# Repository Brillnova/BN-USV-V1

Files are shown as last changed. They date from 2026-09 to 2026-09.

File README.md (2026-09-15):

# BN-USV V1

BN-USV V1 is an experimental unmanned surface vehicle reference prototype by Brillnova. It was developed to validate the control architecture, navigation software and on-water behavior of a Raspberry Pi and ESP32-based USV.

V1 is **not a commercial product**, is **not for sale**, and is **not a ready-to-print DIY kit**. It is shared as a technical reference. The hull requires substantial post-processing, bonding and waterproofing, and is not optimized for easy reproduction.

For the next platform direction and Brillnova updates, see the [Brillnova website](https://brillnova.net), [GitHub](https://github.com/Brillnova), and [YouTube](https://www.youtube.com/@Brillnova).

## Included in this release

- Raspberry Pi navigation and control reference software
- ESP32 propulsion-control firmware, with OTA disabled until local credentials are configured
- Minimal dependency list and local configuration template
- V1 reference hull STL meshes and a FreeCAD assembly composed from those meshes
- Assembly and reference-hull licensing notes

## Not included

- V2 materials, source code or designs
- PCB designs, original CAD, manufacturing files or internal design documents
- Raw field logs, real waypoints, calibration values and network credentials
- BOM and wiring-diagram files; these are not part of this initial release

## Quick start

1. Review [assembly notes](docs/ASSEMBLY_NOTES.md) and the limitations below.
2. Copy `software/config.example.py` to `software/config.py`, then enter local ports, waypoints and calibration values. Do not commit this file.
3. Install the Python dependencies: `python3 -m pip install -r software/requirements.txt`.
4. Review the pin assignments and safety behavior in `firmware/BN_USV_V0.3.1/BN_USV_V0.3.1.ino` before flashing it to an ESP32.
5. Keep OTA disabled or set local credentials only in your working copy.

The software expects sensor hardware and system dependencies not bundled in this repository. This is a reference implementation, not a turnkey installation guide.

## Known limitations

- Hull assembly requires significant bonding and waterproofing.
- The design has limited modularity and difficult access to internal components.
- Wiring is prototype-oriented.
- Assembly support, success guarantees and performance guarantees are not provided.
- The BOM for future releases will include only parts directly tested by Brillnova; alternatives are not validated.

## Licensing

Unless a file states otherwise, the software in this repository is released under the [MIT License](LICENSE).

The V1 reference hull meshes and the FreeCAD mesh assembly are licensed separately under [CC BY-NC-SA 4.0](docs/REFERENCE_HULL_FILES.md). Branding, photographs and videos are not licensed for reuse by the software license.

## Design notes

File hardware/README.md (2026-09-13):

# V1 reference hull files

`stl/` contains the V1 hull mesh files used for the reference prototype.

`assembly/BN_USV_V1.FCStd` is a FreeCAD project composed from those STL meshes. It is included for reference and mesh arrangement; it is not the original parametric CAD source.

See [Reference hull files](../docs/REFERENCE_HULL_FILES.md) for the CC BY-NC-SA 4.0 terms, scope and attribution requirements. V1 requires substantial post-processing, bonding and waterproofing and is not a turnkey DIY kit.

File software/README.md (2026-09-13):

# V1 reference software

This folder contains the Raspberry Pi-side reference implementation for V1 navigation, sensor input, propulsion commands and runtime logging. It is intended for inspection and adaptation, not as a turnkey deployment package.

## Before running

Copy `config.example.py` to `config.py`, then set your local serial ports, waypoint coordinates and magnetometer calibration values. `config.py` is deliberately ignored by Git so local settings and test locations are not published.

Install the minimal Python dependencies with:

```bash
python3 -m pip install -r requirements.txt
```

`main_v4.py` is the main application entry point. It expects the configured sensors and an ESP32 connection to be available.

## Files

| File | Purpose |
| --- | --- |
| `main_v4.py` | Runs the V1 mission loop: reads sensors, calculates navigation and control output, sends commands to the ESP32, and records state. |
| `config.example.py` | Template for local ports, waypoints, arrival radius and magnetometer calibration. Copy it to `config.py` before use. |
| `gps.py` | Reads and parses GPS/NMEA position, speed and course information. |
| `mag.py` | Reads the LIS3MDL magnetometer and applies heading calibration values. |
| `mag_calibration.py` | Updates magnetometer heading calibration from GPS-course comparisons when suitable data is available. |
| `imu.py` | Reads IMU acceleration and angular-rate data. |
| `battery.py` | Reads the INA226 battery monitor and estimates voltage, current and state of charge. |
| `navigation.py` | Calculates distance, bearing and normalized heading error to the current waypoint. |
| `controller.py` | Converts distance and heading error into throttle and steering commands. |
| `esp_link.py` | Exchanges JSON-line control commands and telemetry with the ESP32 over serial. |
| `logger.py` | Writes navigation, sensor, battery and control state to CSV and JSONL logs. |
| `requirements.txt` | Minimal Python dependency list for the reference software. |

## Operational notes

The reference controller and all safety thresholds need review and testing for the vessel, sensors and operating conditions in use. Test with propulsion safely restrained or disconnected before water operation. Raw logs are not included in this public repository.

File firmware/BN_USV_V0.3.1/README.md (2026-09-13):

# BN_USV_V0.3.1 ESP32 firmware

`BN_USV_V0.3.1.ino` is the V1 ESP32-S3 reference firmware. It reads RC PWM input, drives the left and right ESC outputs, accepts serial commands from the Raspberry Pi, and emits JSON-line telemetry.

## What it does

- Reads RC steering, throttle and mode-switch channels.
- Drives separate left and right ESC PWM outputs.
- Accepts `cmd_manual` JSON-line commands from the Raspberry Pi over USB serial.
- Applies manual override, neutral re-arm and command-freshness checks.
- Moves to a neutral/failsafe state when RC or Pi commands time out.
- Reports periodic `telemetry_status` messages over serial.
- Supports optional Arduino OTA updates, disabled by default in this public release.

## Before uploading

Review the user-configuration section near the top of the sketch for your hardware:

| Setting | Default | Purpose |
| --- | --- | --- |
| `RC_CH1_PIN`, `RC_CH2_PIN`, `RC_CH4_PIN` | `4`, `5`, `6` | RC steering, throttle and mode-switch PWM input pins. |
| `ESC_L_PIN`, `ESC_R_PIN` | `1`, `2` | Left and right ESC PWM output pins. |
| `UART_BAUD` | `115200` | USB serial speed used for Raspberry Pi communication. |
| `PWM_MIN_US`, `PWM_MAX_US`, `PWM_NEU_US` | `1000`, `2000`, `1500` | ESC output range and neutral value. |
| `RC_TIMEOUT_MS`, `CH4_TIMEOUT_MS`, `PI_TIMEOUT_MS` | `300`, `500`, `500` | Input freshness limits that trigger safety behavior. |
| `OTA_SSID`, `OTA_PASSWORD` | empty | OTA is disabled while the SSID is empty. Keep any local credentials out of Git. |

The default pins and thresholds came from the V1 prototype. They are not universal values and must be checked against the actual board, receiver, ESCs and propulsion system.

## Dependencies and upload

Install the Arduino core for ESP32 and the `ESP32Servo` library in the Arduino IDE or Arduino CLI environment, then select the appropriate ESP32-S3 board and serial port before uploading. `WiFi.h` and `ArduinoOTA.h` come from the ESP32 Arduino core.

Keep OTA disabled unless you have configured local credentials in an uncommitted working copy.

## Safety check

Before connecting propulsion, confirm the configured pin mapping, neutral PWM value, RC mode behavior and serial-command timeout. Test with propellers removed or the vessel safely restrained. This is prototype firmware and does not provide a guarantee of safe operation in another hardware configuration.

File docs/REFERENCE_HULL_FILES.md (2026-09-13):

# V1 reference hull files

This release includes the V1 reference hull mesh files in [`hardware/stl`](../hardware/stl), plus the [`BN_USV_V1.FCStd`](../hardware/assembly/BN_USV_V1.FCStd) FreeCAD assembly and a preview image in [`hardware/assembly`](../hardware/assembly).

The FreeCAD project is an assembly of the released STL meshes. It is provided for viewing and arranging those meshes; it is not the original parametric CAD source.

## License and scope

The STL files in `hardware/stl` and the `hardware/assembly/BN_USV_V1.FCStd` assembly are **V1 Reference Hull Files** and are licensed under [CC BY-NC-SA 4.0](https://creativecommons.org/licenses/by-nc-sa/4.0/).

This permits noncommercial personal fabrication, modification and redistribution, provided that you:

- Credit **Brillnova**, retain a link to the source and license, and identify any changes.
- Distribute modified V1 Reference Hull Files under the same CC BY-NC-SA 4.0 license.
- Do not use the files for commercial purposes or imply Brillnova endorsement.

Suggested attribution:

> BN-USV V1 Reference Hull Files by Brillnova. Source: https://github.com/Brillnova/BN-USV-V1. Licensed under CC BY-NC-SA 4.0: https://creativecommons.org/licenses/by-nc-sa/4.0/. Changes: [describe changes, or state unmodified].

Original parametric CAD, PCB designs, other manufacturing files and all V2 designs are excluded from this license unless Brillnova separately releases them.

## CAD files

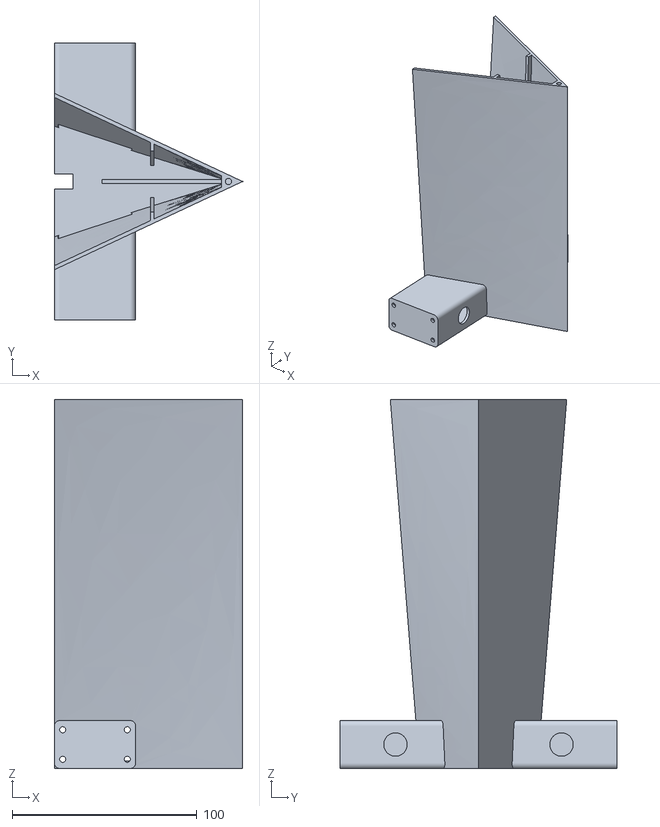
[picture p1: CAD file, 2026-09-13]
hardware/stl/Main Hull 3_4.stl
102.0 x 150.0 x 200.0

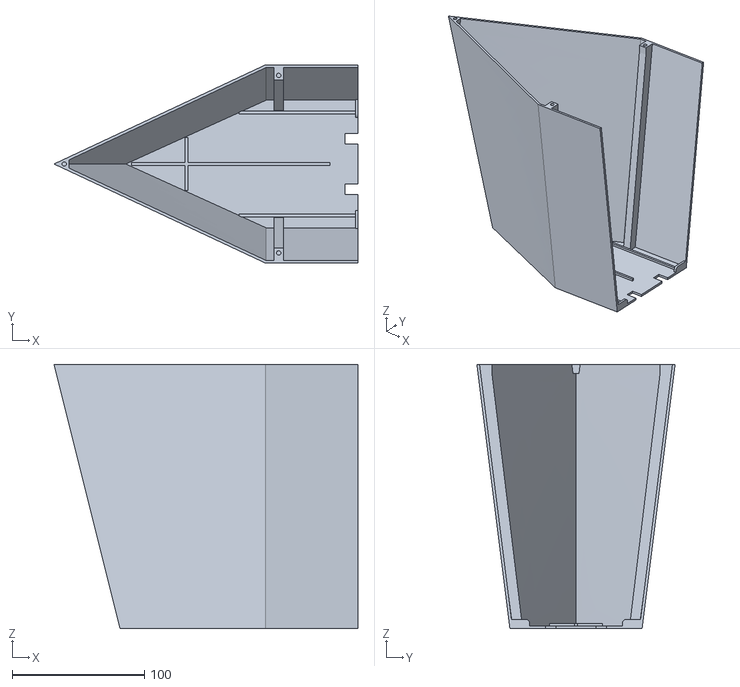
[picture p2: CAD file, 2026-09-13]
hardware/stl/Main Hull 1_4.stl
230.0 x 150.0 x 200.0

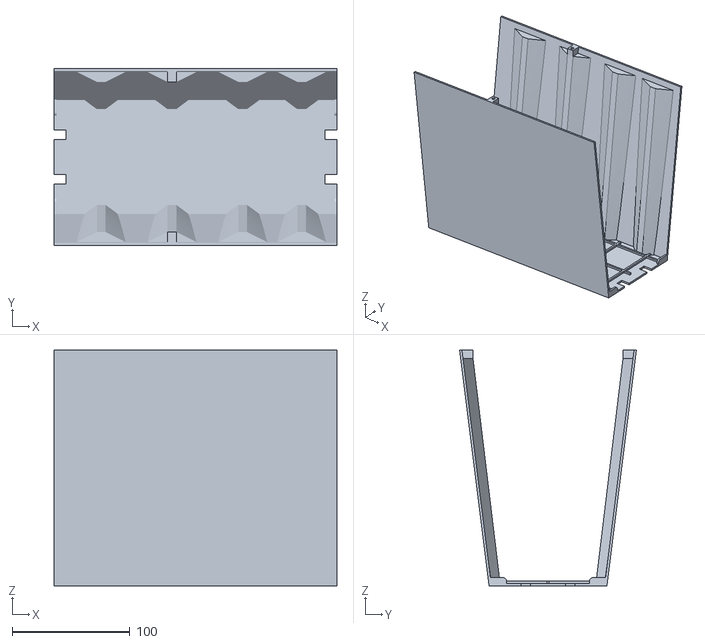
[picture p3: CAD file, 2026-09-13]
hardware/stl/Main Hull 4_4.stl
240.0 x 150.0 x 200.0

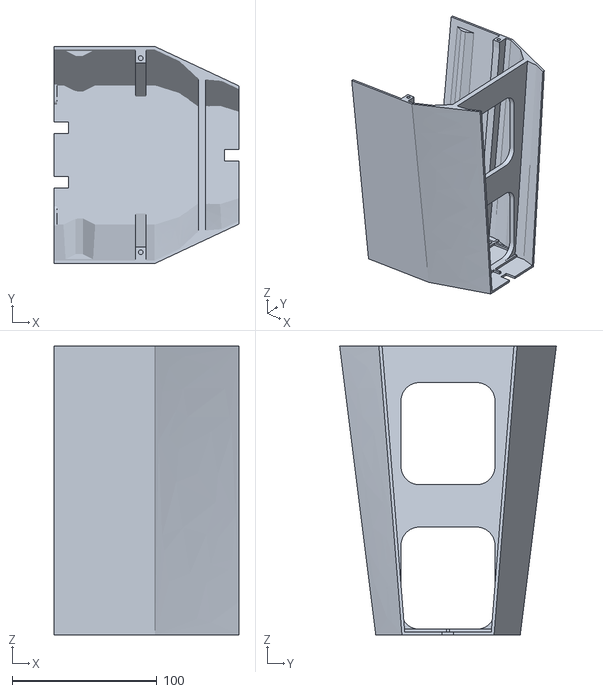
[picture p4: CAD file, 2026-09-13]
hardware/stl/Main Hull 2_4.stl
128.0 x 150.0 x 200.0

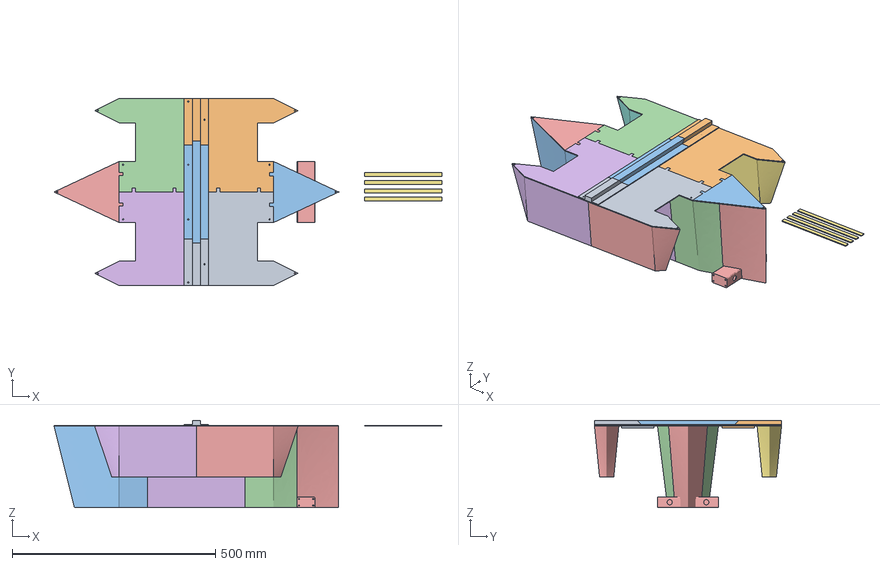
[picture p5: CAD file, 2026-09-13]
hardware/assembly/BN_USV_V1.FCStd
954.0 x 460.0 x 214.0 mm
Hatch Cover 1/6
Hatch Cover 2/6
Hatch Cover_3/6
Hatch Cover_4/6
Hatch Cover_5/6
Hatch Cover_6/6
PCB Mounting Plate 2_2
PCB Mounting Plate 1_2
Hatch Cover Transverse Stiffener 4_4
Hatch Cover Transverse Stiffener 3_4
Hatch Cover Transverse Stiffener 2_4
Hatch Cover Transverse Stiffener 1_4
Outrigger Hull 1_4
Outrigger Hull 2_4
Outrigger Hull 3_4
Outrigger Hull 4_4
Outrigger Stiffener
Hull Joining Sleeve 1_5
Main Hull 1_4
Main Hull 2_4
Main Hull 3_4
Main Hull 4_4
Hull Joining Sleeve 2_5
Hull Joining Sleeve 3_5
Hull Joining Sleeve 4_5
Hull Joining Sleeve 5_5

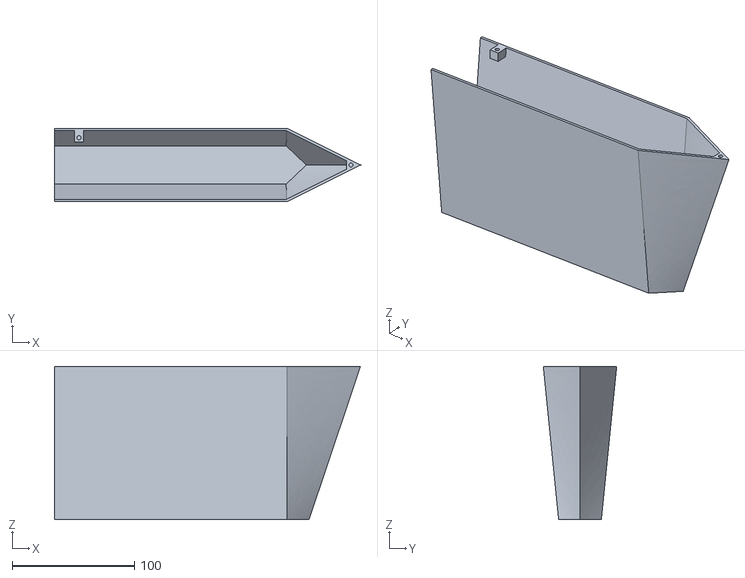
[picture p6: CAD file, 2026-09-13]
hardware/stl/Outrigger Hull 1_4.stl
250.0 x 60.0 x 125.0

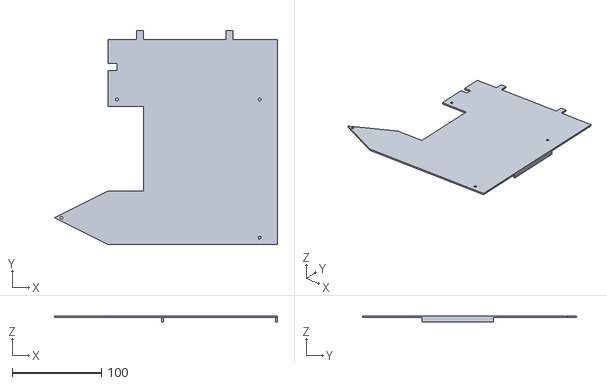
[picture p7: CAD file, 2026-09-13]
hardware/stl/Hatch Cover 6_6.stl
250.0 x 240.0 x 7.00

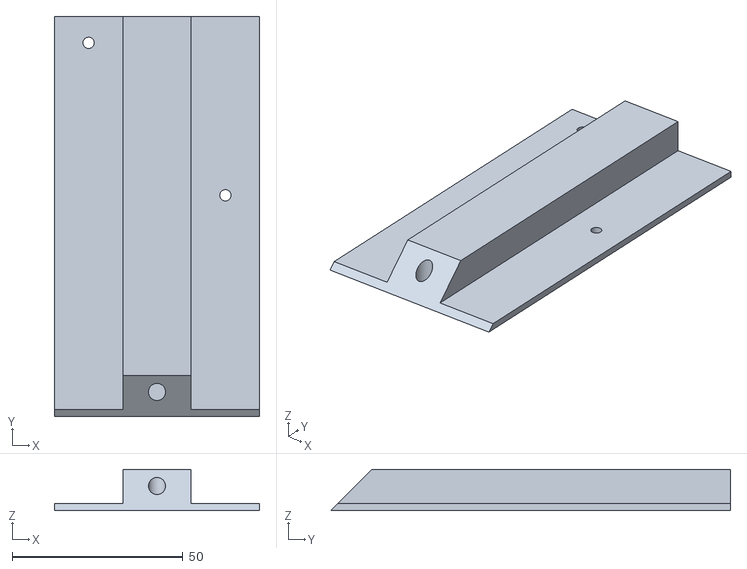
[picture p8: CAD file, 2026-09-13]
hardware/stl/Hatch Cover Transverse Stiffener 3_4.stl
60.0 x 117.0 x 12.0

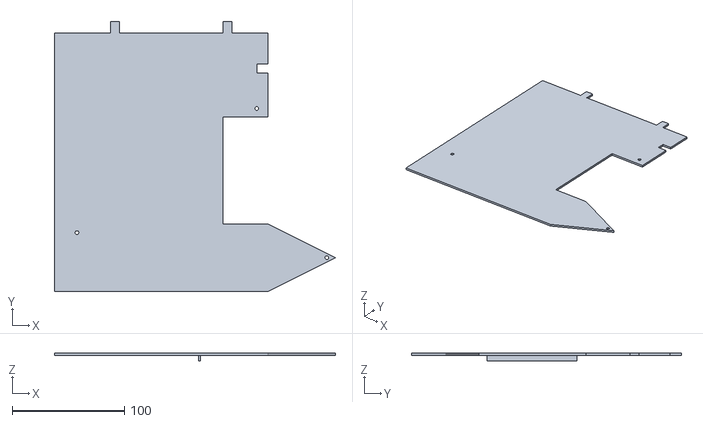
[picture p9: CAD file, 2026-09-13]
hardware/stl/Hatch Cover 1_6.stl
250.0 x 240.0 x 7.00

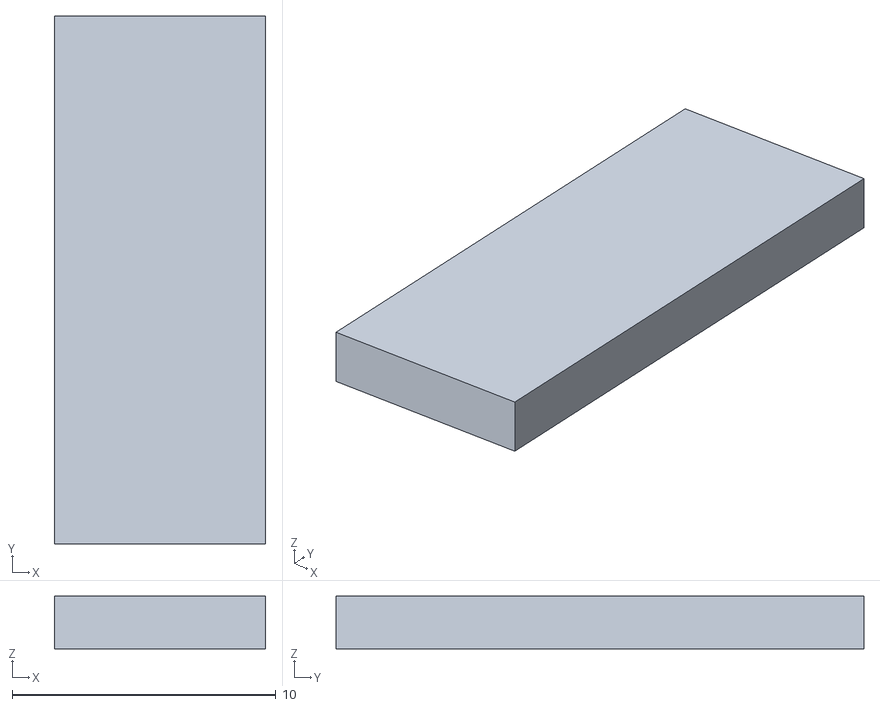
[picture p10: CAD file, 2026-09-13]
hardware/stl/Hull Joining Sleeve 1_5.stl
8.00 x 20.0 x 2.00

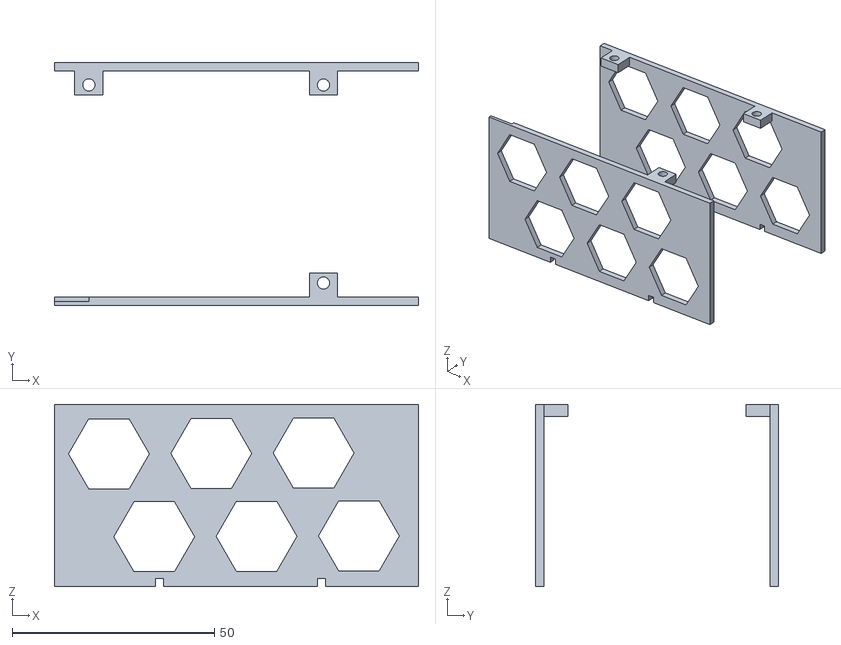
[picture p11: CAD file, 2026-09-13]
hardware/stl/PCB Mounting Plate 2_2.stl
90.0 x 60.0 x 45.0

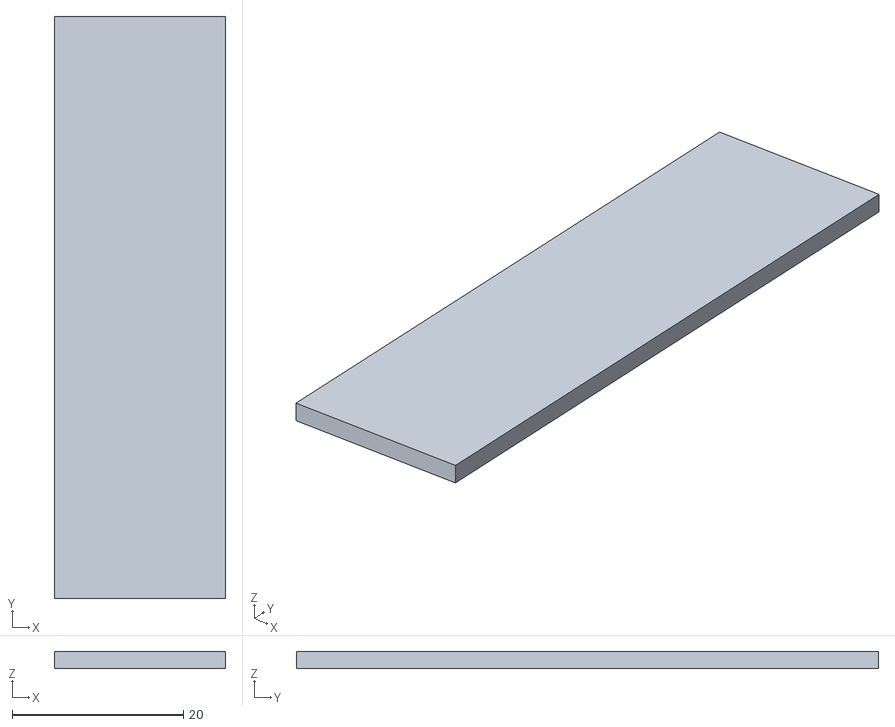
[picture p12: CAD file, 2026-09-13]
hardware/stl/Hull Joining Sleeve 4_5.stl
20.0 x 68.0 x 2.00

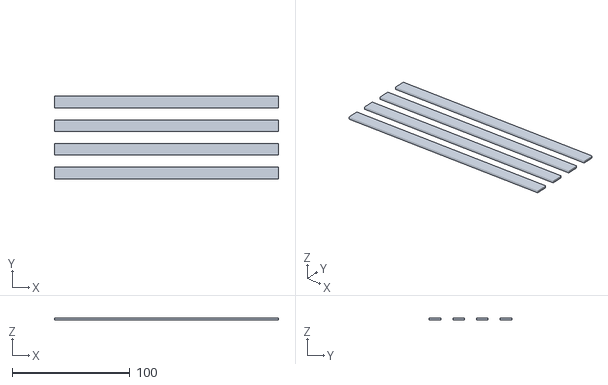
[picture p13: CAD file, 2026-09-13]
hardware/stl/Hull Joining Sleeve 2_5.stl
190.0 x 70.0 x 2.00

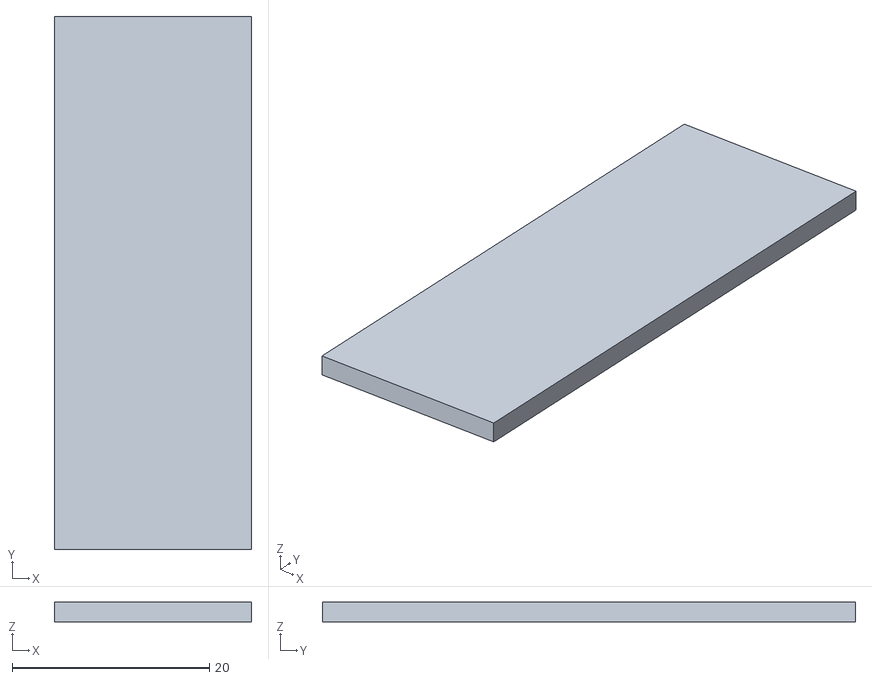
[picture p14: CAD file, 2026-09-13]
hardware/stl/Hull Joining Sleeve 5_5.stl
20.0 x 54.0 x 2.00

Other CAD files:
hardware/stl/Outrigger Hull 4_4.stl
hardware/stl/Outrigger Hull 3_4.stl
hardware/stl/Hull Joining Sleeve 3_5.stl
hardware/stl/Hatch Cover 5_6.stl
hardware/stl/Hatch Cover 2_6.stl
hardware/stl/Hatch Cover 3_6.stl
hardware/stl/Hatch Cover 4_6.stl
hardware/stl/Hatch Cover Transverse Stiffener 1_4.stl
hardware/stl/Hatch Cover Transverse Stiffener 2_4.stl
hardware/stl/Hatch Cover Transverse Stiffener 4_4.stl
hardware/stl/Outrigger Hull 2_4.stl
hardware/stl/PCB Mounting Plate 1_2.stl

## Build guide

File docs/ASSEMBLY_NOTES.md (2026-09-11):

# Assembly notes

V1 is an experimental reference prototype. Its hull requires substantial post-processing, bonding and waterproofing. The project does not provide individual build support or guarantees of assembly success, seaworthiness or performance.

Use only a configuration appropriate for your operating environment. Inspect every waterproofing point and confirm neutral propulsion output, manual override and failsafe behavior before testing. Conduct initial tests in a controlled environment and follow applicable local rules.

The BOM for a future release will list only components tested by Brillnova. Substitute parts are not validated.

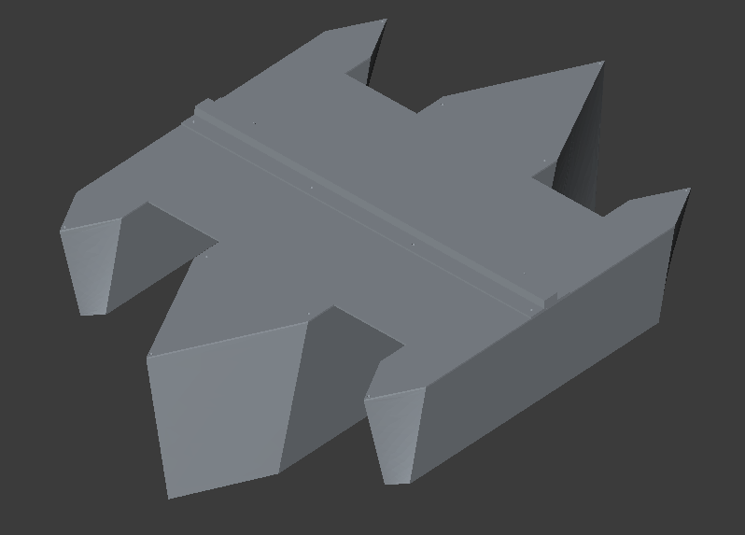
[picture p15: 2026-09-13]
hardware/assembly/BN_USV_V1.png

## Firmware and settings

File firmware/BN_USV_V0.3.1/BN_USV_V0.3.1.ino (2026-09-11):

#include <Arduino.h>
#include <ESP32Servo.h>
#include <WiFi.h>
#include <ArduinoOTA.h>

// =====================
// Debug configuration
// =====================
#define DEBUG_MODE 0  // 1 = enable debug prints, 0 = disable for Pi communication

#if DEBUG_MODE
  #define DBG_PRINT(x)     Serial.print(x)
  #define DBG_PRINTLN(x)   Serial.println(x)
  #define DBG_PRINTF(...)  Serial.printf(__VA_ARGS__)
#else
  #define DBG_PRINT(x)
  #define DBG_PRINTLN(x)
  #define DBG_PRINTF(...)
#endif

// =====================
// User configuration
// =====================

// RC PWM input pins
static const int RC_CH1_PIN = 4;  // Steering PWM input
static const int RC_CH2_PIN = 5;  // Throttle PWM input
static const int RC_CH4_PIN = 6;  // Mode switch PWM input

// ESC output pins
static const int ESC_L_PIN = 1;  // Left ESC PWM output
static const int ESC_R_PIN = 2;  // Right ESC PWM output

// USB Serial baud rate for Raspberry Pi <-> ESP32 communication
static const int UART_BAUD = 115200;

// OTA configuration
// Leave OTA_SSID empty to disable OTA and keep USB-only operation.
static const char *OTA_SSID = "";  // Set your network name to enable OTA.
static const char *OTA_PASSWORD = "";  // Keep local; do not commit credentials.
static const char *OTA_HOSTNAME = "BN-USV-ESP32S3";
static bool otaEnabled = false;

// PWM limits
static const int PWM_MIN_US = 1000;
static const int PWM_MAX_US = 2000;
static const int PWM_NEU_US = 1500;

// RC processing
static const int DEADBAND_US = 20;

// Safety timeouts
static const uint32_t RC_TIMEOUT_MS = 300;
static const uint32_t CH4_TIMEOUT_MS = 500;
static const uint32_t PI_TIMEOUT_MS = 500;  // Protocol baseline: >500 ms -> failsafe
static const uint32_t STATUS_PERIOD_MS = 500;  // JSON status telemetry period

// RC override latch
static const int OVERRIDE_THRESH_US = 220;
static const int AUTO_ARM_DEADBAND_US = 60;

// Serial RX buffer
static const size_t RX_LINE_MAX = 256;

// Slew rate limiter (us per second)
static const float SLEW_ACCEL_US_PER_S = 250.0f;
static const float SLEW_DECEL_US_PER_S = 2000.0f;

// =====================
// Global types
// =====================

enum ControlMode {
  MODE_MANUAL = 0,
  MODE_AUTO,
  MODE_KILL,
  MODE_FAILSAFE
};

// =====================
// Globals
// =====================

Servo escL;
Servo escR;

static int escL_out_us = PWM_NEU_US;
static int escR_out_us = PWM_NEU_US;
static uint32_t lastSlewMs = 0;

static bool manualLatch = false;
static ControlMode lastRcMode = MODE_MANUAL;

// RC capture state
volatile uint32_t ch1Rise = 0;
volatile uint32_t ch2Rise = 0;
volatile uint32_t ch4Rise = 0;
volatile uint16_t ch1Us = PWM_NEU_US;
volatile uint16_t ch2Us = PWM_NEU_US;
volatile uint16_t ch4Us = PWM_NEU_US;
volatile uint32_t ch1LastOk = 0;
volatile uint32_t ch2LastOk = 0;
volatile uint32_t ch4LastOk = 0;

// Pi command state
static uint16_t piThrUs = PWM_NEU_US;
static uint16_t piStrUs = PWM_NEU_US;
static float piThrNorm = 0.0f;
static float piStrNorm = 0.0f;
static long piCmdSeq = -1;
static uint32_t piLastRxMs = 0;

// =====================
// Utility functions
// =====================

static inline int clampInt(int value, int minValue, int maxValue) {
  if (value < minValue) return minValue;
  if (value > maxValue) return maxValue;
  return value;
}

static inline float clampFloat(float value, float minValue, float maxValue) {
  if (value < minValue) return minValue;
  if (value > maxValue) return maxValue;
  return value;
}

static inline int applyDeadband(int value, int deadband) {
  if (abs(value) <= deadband) return 0;
  return value;
}

static uint16_t normalizedToPwm(float value) {
  value = clampFloat(value, -1.0f, 1.0f);
  int pwm = PWM_NEU_US + (int)(value * 500.0f);
  return (uint16_t)clampInt(pwm, PWM_MIN_US, PWM_MAX_US);
}

static int applySlewAroundNeutral(int current, int target, float accelRate, float decelRate, float dt_s) {
  if (dt_s <= 0.0f) return current;
  if (current == target) return current;

  int currentDev = current - PWM_NEU_US;
  int targetDev = target - PWM_NEU_US;

  bool movingAwayFromNeutral = abs(targetDev) > abs(currentDev);
  float rate = movingAwayFromNeutral ? accelRate : decelRate;

  int maxStep = (int)(rate * dt_s + 0.5f);
  if (maxStep < 1) maxStep = 1;

  int diff = target - current;
  if (diff > 0) {
    return current + min(diff, maxStep);
  }

  return current - min(-diff, maxStep);
}

static void writeNeutralImmediate() {
  escL_out_us = PWM_NEU_US;
  escR_out_us = PWM_NEU_US;
  escL.writeMicroseconds(PWM_NEU_US);
  escR.writeMicroseconds(PWM_NEU_US);
}

// =====================
// RC interrupt handlers
// =====================

void IRAM_ATTR isr_ch1() {
  if (digitalRead(RC_CH1_PIN)) {
    ch1Rise = micros();
  } else {
    uint32_t width = micros() - ch1Rise;
    if (width >= 900 && width <= 2100) {
      ch1Us = (uint16_t)width;
      ch1LastOk = millis();
    }
  }
}

void IRAM_ATTR isr_ch2() {
  if (digitalRead(RC_CH2_PIN)) {
    ch2Rise = micros();
  } else {
    uint32_t width = micros() - ch2Rise;
    if (width >= 900 && width <= 2100) {
      ch2Us = (uint16_t)width;
      ch2LastOk = millis();
    }
  }
}

void IRAM_ATTR isr_ch4() {
  if (digitalRead(RC_CH4_PIN)) {
    ch4Rise = micros();
  } else {
    uint32_t width = micros() - ch4Rise;
    if (width >= 900 && width <= 2100) {
      ch4Us = (uint16_t)width;
      ch4LastOk = millis();
    }
  }
}


static const char *modeToString(ControlMode mode);

// =====================
// JSON response helpers
// =====================

static void sendAck(long seq, float throttle, float steering, uint16_t thrUs, uint16_t strUs) {
  Serial.print("{\"type\":\"ack\",");
  Serial.print("\"timestamp\":");
  Serial.print(millis() / 1000.0f, 3);
  Serial.print(",\"seq\":");
  Serial.print(seq);
  Serial.print(",\"data\":{");
  Serial.print("\"accepted\":true,");
  Serial.print("\"throttle\":");
  Serial.print(throttle, 3);
  Serial.print(",\"steering\":");
  Serial.print(steering, 3);
  Serial.print(",\"thr_us\":");
  Serial.print(thrUs);
  Serial.print(",\"str_us\":");
  Serial.print(strUs);
  Serial.println("}}");
}

static void sendReject(long seq, const char *reason) {
  Serial.print("{\"type\":\"ack\",");
  Serial.print("\"timestamp\":");
  Serial.print(millis() / 1000.0f, 3);
  Serial.print(",\"seq\":");
  Serial.print(seq);
  Serial.print(",\"data\":{");
  Serial.print("\"accepted\":false,");
  Serial.print("\"reason\":\"");
  Serial.print(reason);
  Serial.println("\"}}");
}

static void sendStatus(ControlMode mode, ControlMode rcMode, bool rcOk, bool piFresh,
                       uint16_t ch1, uint16_t ch2, uint16_t ch4,
                       uint16_t cmdThr, uint16_t cmdStr,
                       int leftOutUs, int rightOutUs) {
  Serial.print("{\"type\":\"telemetry_status\",");
  Serial.print("\"timestamp\":");
  Serial.print(millis() / 1000.0f, 3);
  Serial.print(",\"seq\":");
  Serial.print(piCmdSeq);
  Serial.print(",\"data\":{");
  Serial.print("\"mode\":\"");
  Serial.print(modeToString(mode));
  Serial.print("\",");
  Serial.print("\"rc_mode\":\"");
  Serial.print(modeToString(rcMode));
  Serial.print("\",");
  Serial.print("\"rc_ok\":");
  Serial.print(rcOk ? "true" : "false");
  Serial.print(",\"pi_fresh\":");
  Serial.print(piFresh ? "true" : "false");
  Serial.print(",\"manual_latch\":");
  Serial.print(manualLatch ? "true" : "false");
  Serial.print(",\"ch1_us\":");
  Serial.print(ch1);
  Serial.print(",\"ch2_us\":");
  Serial.print(ch2);
  Serial.print(",\"ch4_us\":");
  Serial.print(ch4);
  Serial.print(",\"cmd_thr_us\":");
  Serial.print(cmdThr);
  Serial.print(",\"cmd_str_us\":");
  Serial.print(cmdStr);
  Serial.print(",\"left_pwm\":");
  Serial.print(leftOutUs);
  Serial.print(",\"right_pwm\":");
  Serial.print(rightOutUs);
  Serial.println("}}");
}

// =====================
// Pi command parsing
// =====================

static bool extractJsonNumber(const String &line, const char *key, float &outValue) {
  String quotedKey = String("\"") + key + "\"";
  int keyIndex = line.indexOf(quotedKey);
  if (keyIndex < 0) return false;

  int colonIndex = line.indexOf(':', keyIndex + quotedKey.length());
  if (colonIndex < 0) return false;

  int start = colonIndex + 1;
  while (start < (int)line.length() && isspace((unsigned char)line[start])) {
    start++;
  }

  int end = start;
  while (end < (int)line.length()) {
    char c = line[end];
    if ((c >= '0' && c <= '9') || c == '-' || c == '+' || c == '.') {
      end++;
    } else {
      break;
    }
  }

  if (end == start) return false;

  outValue = line.substring(start, end).toFloat();
  return true;
}

static bool parseJsonManualCommand(const String &line, uint16_t &thrOut, uint16_t &strOut, float &thrNormOut, float &strNormOut, long &seqOut) {
  if (line.indexOf("\"type\"") < 0 || line.indexOf("cmd_manual") < 0) {
    return false;
  }

  float throttle = 0.0f;
  float steering = 0.0f;
  float seqFloat = -1.0f;

  extractJsonNumber(line, "seq", seqFloat);
  seqOut = (long)seqFloat;

  if (!extractJsonNumber(line, "throttle", throttle)) return false;
  if (!extractJsonNumber(line, "steering", steering)) return false;

  if (throttle < -1.0f || throttle > 1.0f) return false;
  if (steering < -1.0f || steering > 1.0f) return false;

  thrNormOut = throttle;
  strNormOut = steering;
  thrOut = normalizedToPwm(throttle);
  strOut = normalizedToPwm(steering);
  return true;
}

static bool parseLegacyCsvCommand(const String &line, uint16_t &thrOut, uint16_t &strOut, float &thrNormOut, float &strNormOut, long &seqOut) {
  int commaIndex = line.indexOf(',');
  if (commaIndex < 0) return false;

  String thrText = line.substring(0, commaIndex);
  String strText = line.substring(commaIndex + 1);
  thrText.trim();
  strText.trim();

  if (thrText.length() == 0 || strText.length() == 0) return false;

  long throttle = thrText.toInt();
  long steering = strText.toInt();

  if (throttle < PWM_MIN_US || throttle > PWM_MAX_US) return false;
  if (steering < PWM_MIN_US || steering > PWM_MAX_US) return false;

  thrOut = (uint16_t)throttle;
  strOut = (uint16_t)steering;
  thrNormOut = ((float)thrOut - PWM_NEU_US) / 500.0f;
  strNormOut = ((float)strOut - PWM_NEU_US) / 500.0f;
  seqOut = -1;
  return true;
}

static bool parsePiLine(const String &line, uint16_t &thrOut, uint16_t &strOut,
                        float &thrNormOut, float &strNormOut, long &seqOut) {
  if (parseJsonManualCommand(line, thrOut, strOut, thrNormOut, strNormOut, seqOut)) return true;

  // Keep legacy CSV support for bench testing only.
  if (parseLegacyCsvCommand(line, thrOut, strOut, thrNormOut, strNormOut, seqOut)) return true;

  return false;
}

// =====================
// Mode handling
// =====================

static ControlMode getModeFromCH4(uint16_t ch4) {
  if (ch4 < 1300) return MODE_MANUAL;
  if (ch4 < 1700) return MODE_AUTO;
  return MODE_KILL;
}

static const char *modeToString(ControlMode mode) {
  switch (mode) {
    case MODE_MANUAL: return "MANUAL";
    case MODE_AUTO: return "AUTO";
    case MODE_KILL: return "KILL";
    case MODE_FAILSAFE: return "FAILSAFE";
    default: return "UNKNOWN";
  }
}

// =====================
// Arduino lifecycle
// =====================


// =====================
// OTA update
// =====================

void setupOTA() {
  if (strlen(OTA_SSID) == 0) {
    otaEnabled = false;
    DBG_PRINTLN("OTA disabled: OTA_SSID is empty.");
    return;
  }

  WiFi.mode(WIFI_STA);
  WiFi.setHostname(OTA_HOSTNAME);
  WiFi.begin(OTA_SSID, OTA_PASSWORD);

  uint32_t startMs = millis();
  while (WiFi.status() != WL_CONNECTED && (millis() - startMs) < 10000) {
    delay(250);
  }

  if (WiFi.status() != WL_CONNECTED) {
    otaEnabled = false;
    DBG_PRINTLN("OTA disabled: WiFi connection failed.");
    return;
  }

  ArduinoOTA.setHostname(OTA_HOSTNAME);

  ArduinoOTA.onStart([]() {
    // Keep propulsion safe during firmware update.
    writeNeutralImmediate();
    DBG_PRINTLN("OTA update started.");
  });

  ArduinoOTA.onEnd([]() {
    writeNeutralImmediate();
    DBG_PRINTLN("OTA update finished.");
  });

  ArduinoOTA.onError([](ota_error_t error) {
    writeNeutralImmediate();
    DBG_PRINTF("OTA error: %u\n", error);
  });

  ArduinoOTA.begin();
  otaEnabled = true;

  DBG_PRINT("OTA ready. IP: ");
  DBG_PRINTLN(WiFi.localIP());
}

void setup() {
  Serial.begin(UART_BAUD);
  delay(200);

  setupOTA();

  pinMode(RC_CH1_PIN, INPUT);
  pinMode(RC_CH2_PIN, INPUT);
  pinMode(RC_CH4_PIN, INPUT);

  attachInterrupt(digitalPinToInterrupt(RC_CH1_PIN), isr_ch1, CHANGE);
  attachInterrupt(digitalPinToInterrupt(RC_CH2_PIN), isr_ch2, CHANGE);
  attachInterrupt(digitalPinToInterrupt(RC_CH4_PIN), isr_ch4, CHANGE);

  escL.setPeriodHertz(50);
  escR.setPeriodHertz(50);
  escL.attach(ESC_L_PIN, PWM_MIN_US, PWM_MAX_US);
  escR.attach(ESC_R_PIN, PWM_MIN_US, PWM_MAX_US);

  writeNeutralImmediate();
  delay(2000);  // Give ESCs time to arm at neutral.

  piLastRxMs = 0;

  DBG_PRINTLN("BN-USV ESP32 controller started.");
}

void loop() {
  if (otaEnabled) {
    ArduinoOTA.handle();
  }

  // =====================
  // 1) Read Pi USB Serial lines
  // =====================
  static String rxLine;

  while (Serial.available() > 0) {
    char c = (char)Serial.read();

    if (c == '\n') {
      uint16_t thrTmp = PWM_NEU_US;
      uint16_t strTmp = PWM_NEU_US;
      float thrNormTmp = 0.0f;
      float strNormTmp = 0.0f;
      long seqTmp = -1;

      if (parsePiLine(rxLine, thrTmp, strTmp, thrNormTmp, strNormTmp, seqTmp)) {
        piThrUs = thrTmp;
        piStrUs = strTmp;
        piThrNorm = thrNormTmp;
        piStrNorm = strNormTmp;
        piCmdSeq = seqTmp;
        piLastRxMs = millis();
        sendAck(piCmdSeq, piThrNorm, piStrNorm, piThrUs, piStrUs);
      } else if (rxLine.length() > 0) {
        sendReject(-1, "PARSE_ERROR");
      }

      rxLine = "";
    } else if (c != '\r') {
      if (rxLine.length() < RX_LINE_MAX) {
        rxLine += c;
      } else {
        rxLine = "";
      }
    }
  }

  // =====================
  // 2) Snapshot RC inputs
  // =====================
  uint32_t nowMs = millis();

  uint16_t ch1 = ch1Us;
  uint16_t ch2 = ch2Us;
  uint16_t ch4 = ch4Us;

  bool rcOk = true;
  if (nowMs - ch1LastOk > RC_TIMEOUT_MS) rcOk = false;
  if (nowMs - ch2LastOk > RC_TIMEOUT_MS) rcOk = false;
  if (nowMs - ch4LastOk > CH4_TIMEOUT_MS) rcOk = false;

  if (!rcOk) {
    writeNeutralImmediate();
    DBG_PRINTLN("MODE=FAILSAFE | REASON=RC_TIMEOUT");
    delay(10);
    return;
  }

  // =====================
  // 3) Determine RC mode and safety priority
  // =====================
  ControlMode rcMode = getModeFromCH4(ch4);

  if (rcMode == MODE_KILL) {
    manualLatch = false;
    writeNeutralImmediate();
    DBG_PRINTLN("MODE=KILL | OUTPUT=NEUTRAL");
    delay(10);
    return;
  }

  int steerDev = (int)ch1 - PWM_NEU_US;
  int thrDev = (int)ch2 - PWM_NEU_US;

  bool rcOverride = (abs(steerDev) > OVERRIDE_THRESH_US) || (abs(thrDev) > OVERRIDE_THRESH_US);

  if (rcMode == MODE_AUTO && rcOverride) {
    manualLatch = true;
  }

  if (rcMode == MODE_MANUAL) {
    manualLatch = false;
  }

  bool autoArmRequest = false;
  if (lastRcMode == MODE_MANUAL && rcMode == MODE_AUTO) {
    bool sticksNearNeutral =
        (abs(steerDev) < AUTO_ARM_DEADBAND_US) &&
        (abs(thrDev) < AUTO_ARM_DEADBAND_US);

    if (sticksNearNeutral) {
      autoArmRequest = true;
    } else {
      manualLatch = true;
    }
  }

  ControlMode mode = rcMode;
  if (manualLatch && rcMode == MODE_AUTO) {
    mode = MODE_MANUAL;
  }
  if (autoArmRequest) {
    manualLatch = false;
    mode = MODE_AUTO;
  }

  lastRcMode = rcMode;

  // =====================
  // 4) Choose command source
  // =====================
  uint16_t cmdThr = PWM_NEU_US;
  uint16_t cmdStr = PWM_NEU_US;

  bool piFresh = (piLastRxMs != 0) && ((nowMs - piLastRxMs) <= PI_TIMEOUT_MS);

  if (mode == MODE_MANUAL) {
    cmdThr = ch2;
    cmdStr = ch1;
  } else if (mode == MODE_AUTO) {
    if (piFresh) {
      cmdThr = piThrUs;
      cmdStr = piStrUs;
    } else {
      mode = MODE_FAILSAFE;
      cmdThr = PWM_NEU_US;
      cmdStr = PWM_NEU_US;
    }
  }

  // =====================
  // 5) Mix throttle and steering
  // =====================
  int thr = (int)cmdThr - PWM_NEU_US;
  int str = (int)cmdStr - PWM_NEU_US;

  thr = applyDeadband(thr, DEADBAND_US);
  str = applyDeadband(str, DEADBAND_US);

  int leftUs = PWM_NEU_US + thr + str;
  int rightUs = PWM_NEU_US + thr - str;

  leftUs = clampInt(leftUs, PWM_MIN_US, PWM_MAX_US);
  rightUs = clampInt(rightUs, PWM_MIN_US, PWM_MAX_US);

  // =====================
  // 6) Slew limit and output
  // =====================
  if (lastSlewMs == 0) lastSlewMs = nowMs;
  float dt_s = (nowMs - lastSlewMs) / 1000.0f;
  lastSlewMs = nowMs;

  bool forceNeutral = (leftUs == PWM_NEU_US && rightUs == PWM_NEU_US);

  if (forceNeutral || mode == MODE_FAILSAFE) {
    escL_out_us = PWM_NEU_US;
    escR_out_us = PWM_NEU_US;
  } else {
    escL_out_us = applySlewAroundNeutral(
        escL_out_us,
        leftUs,
        SLEW_ACCEL_US_PER_S,
        SLEW_DECEL_US_PER_S,
        dt_s);

    escR_out_us = applySlewAroundNeutral(
        escR_out_us,
        rightUs,
        SLEW_ACCEL_US_PER_S,
        SLEW_DECEL_US_PER_S,
        dt_s);
  }

  escL.writeMicroseconds(escL_out_us);
  escR.writeMicroseconds(escR_out_us);

  // =====================
  // 7) JSON status telemetry
  // =====================
  static uint32_t lastStatusMs = 0;
  if (nowMs - lastStatusMs >= STATUS_PERIOD_MS) {
    lastStatusMs = nowMs;
    sendStatus(
        mode,
        rcMode,
        rcOk,
        piFresh,
        ch1,
        ch2,
        ch4,
        cmdThr,
        cmdStr,
        escL_out_us,
        escR_out_us);
  }

  delay(10);
}

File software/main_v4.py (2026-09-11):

# main.py
import json
import os
import time
from contextlib import suppress

from config import (
    GPS_PORT,
    GPS_BAUD,
    ESP_PORT,
    ESP_BAUD,
    MAG_ADDR,
    WAYPOINTS,
    ARRIVAL_RADIUS,
    MAG_OFFSET_X,
    MAG_OFFSET_Y,
    MAG_SCALE_X,
    MAG_SCALE_Y,
    MAG_AVG_SCALE,
)

from gps import GPS
from mag import Magnetometer
from mag_calibration import MagAutoCalibrator
from navigation import (
    calculate_bearing,
    calculate_distance,
    normalize_angle_error,
)
from controller import calculate_control
from esp_link import EspLink
from logger import USVLogger
from imu import IMU
from battery import BatteryMonitor


PRINT_INTERVAL_SEC = 1.0
ESP_CMD_SEND_INTERVAL_SEC = 0.1  # 10Hz command rate to prevent ESP watchdog timeout
LOOP_SLEEP_SEC = 0.01  # Allow fast loop with polling, actual rate controlled by sleep below


def empty_esp_status():
    """Return an empty ESP telemetry status record for CSV-safe logging."""
    return {
        "esp_mode": "",
        "esp_rc_mode": "",
        "esp_rc_ok": "",
        "esp_pi_fresh": "",
        "esp_manual_latch": "",
        "esp_ch1_us": "",
        "esp_ch2_us": "",
        "esp_ch4_us": "",
        "esp_cmd_thr_us": "",
        "esp_cmd_str_us": "",
        "esp_left_pwm": "",
        "esp_right_pwm": "",
    }


def parse_esp_telemetry_status(responses, previous_status=None):
    """
    Parse the latest telemetry_status message from ESP protocol lines.

    If responses contain only ack/error/debug lines and no telemetry_status,
    keep the previous ESP status instead of overwriting it with blank values.
    """
    status = dict(previous_status or empty_esp_status())

    for response in responses:
        try:
            msg = json.loads(response)
        except (TypeError, json.JSONDecodeError):
            continue

        if msg.get("type") != "telemetry_status":
            continue

        data = msg.get("data", {})
        status["esp_mode"] = data.get("mode", status.get("esp_mode", ""))
        status["esp_rc_mode"] = data.get("rc_mode", status.get("esp_rc_mode", ""))
        status["esp_rc_ok"] = data.get("rc_ok", status.get("esp_rc_ok", ""))
        status["esp_pi_fresh"] = data.get("pi_fresh", status.get("esp_pi_fresh", ""))
        status["esp_manual_latch"] = data.get(
            "manual_latch", status.get("esp_manual_latch", "")
        )
        status["esp_ch1_us"] = data.get("ch1_us", status.get("esp_ch1_us", ""))
        status["esp_ch2_us"] = data.get("ch2_us", status.get("esp_ch2_us", ""))
        status["esp_ch4_us"] = data.get("ch4_us", status.get("esp_ch4_us", ""))
        status["esp_cmd_thr_us"] = data.get(
            "cmd_thr_us", status.get("esp_cmd_thr_us", "")
        )
        status["esp_cmd_str_us"] = data.get(
            "cmd_str_us", status.get("esp_cmd_str_us", "")
        )
        status["esp_left_pwm"] = data.get("left_pwm", status.get("esp_left_pwm", ""))
        status["esp_right_pwm"] = data.get(
            "right_pwm", status.get("esp_right_pwm", "")
        )

    return status


def get_cpu_temperature():
    """Read Raspberry Pi CPU temperature in degrees Celsius, if available."""
    for path in (
        "/sys/class/thermal/thermal_zone0/temp",
        "/sys/class/thermal/thermal_zone1/temp",
    ):
        if not os.path.exists(path):
            continue

        try:
            with open(path, "r", encoding="utf-8") as temp_file:
                raw = temp_file.read().strip()
            return float(raw) / 1000.0
        except (OSError, ValueError):
            return None

    return None


def print_runtime_status(
    *,
    mission_state,
    waypoint_index,
    waypoint_total,
    distance,
    heading_error,
    speed,
    throttle,
    steering,
    battery_v,
    battery_a,
    battery_coulomb_soc,
    esp_status=None,
    pi_loop_dt=None,
    esp_response_count=0,
    gps_hdop=None,
    gps_satellites=None,
    gps_fix_quality=None,
    cpu_temp_c=None,
):
    """Print compact runtime status for operator monitoring."""
    print("\n-----------------------------")
    print(f"State: {mission_state}")
    print(f"Waypoint: {waypoint_index}/{waypoint_total}")
    print(f"Distance: {distance:.1f} m")
    print(f"Heading Error: {heading_error:.1f} deg")
    print(f"Speed: {speed:.2f} m/s")
    print(
        "GPS: "
        f"HDOP={gps_hdop if gps_hdop is not None else ''}, "
        f"SAT={gps_satellites if gps_satellites is not None else ''}, "
        f"FIX={gps_fix_quality if gps_fix_quality is not None else ''}"
    )
    print(f"Command: throttle={throttle:.2f}, steering={steering:.2f}")
    if cpu_temp_c is not None:
        print(f"CPU temp: {cpu_temp_c:.1f} C")
    print(
        f"Battery: {battery_v:.2f} V, "
        f"{battery_a:.2f} A, "
        f"SOC={battery_coulomb_soc:.1f}%"
    )

    if esp_status:
        print(
            "ESP: "
            f"mode={esp_status.get('esp_mode', '')}, "
            f"rc_mode={esp_status.get('esp_rc_mode', '')}, "
            f"rc_ok={esp_status.get('esp_rc_ok', '')}, "
            f"pi_fresh={esp_status.get('esp_pi_fresh', '')}, "
            f"L={esp_status.get('esp_left_pwm', '')}, "
            f"R={esp_status.get('esp_right_pwm', '')}"
        )

    if pi_loop_dt is not None:
        print(f"Pi loop: {pi_loop_dt:.3f} s")

    print(f"ESP responses logged: {esp_response_count}")


def has_gps_fix(lat, lon, gps_fix_quality):
    return lat is not None and lon is not None and gps_fix_quality is not None and gps_fix_quality > 0
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

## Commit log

2026-09-11 feat: publish V1 reference prototype
2026-09-13 docs: describe V1 ESP32 firmware
2026-09-13 feat: publish V1 reference hardware
    [BN_USV_V1.FCStd, Hatch Cover 1_6.stl, Hatch Cover 2_6.stl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]
2026-09-13 docs: describe released V1 hull files
